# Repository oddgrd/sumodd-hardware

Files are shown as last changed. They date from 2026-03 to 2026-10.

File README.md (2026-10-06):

# Sumodd motherboard PCB schematic and layout

This repository holds the schematic and PCB layout files for the
[Sumodd](https://github.com/oddgrd/sumodd) mini-sumo robot motherboard, as well as documentation
for the layout of the various components. For the custom ranging sensor daughterboards, see the
[Auge repo](https://github.com/oddgrd/auge).

When a new iteration of the PCB is manufactured, the latest included commit is tagged with a
version number, e.g. `v0.3`. All parts are specified with Digikey part numbers, in the symbols
`Part number` field.

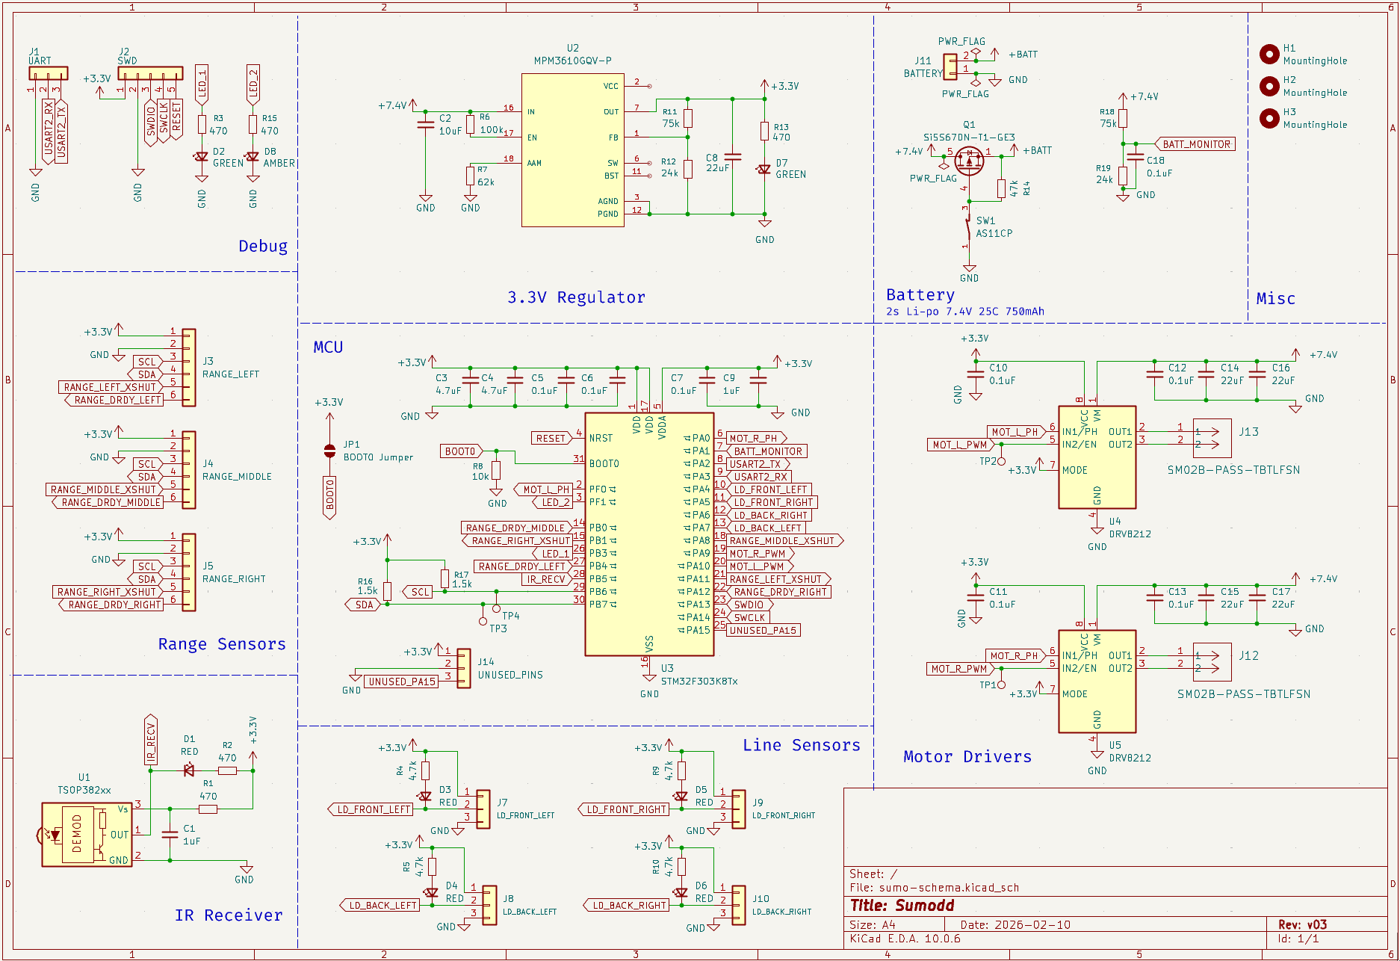
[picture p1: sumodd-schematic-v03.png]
Sumodd motherboard schematic


## PCB stackup

The board has four copper layers, with a total thickness of 1.6mm.

1. F.Cu — components, signal traces and power traces
2. In1.Cu — GND plane
3. In2.Cu — 3.3V power plane
4. B.Cu — signal routing overflow

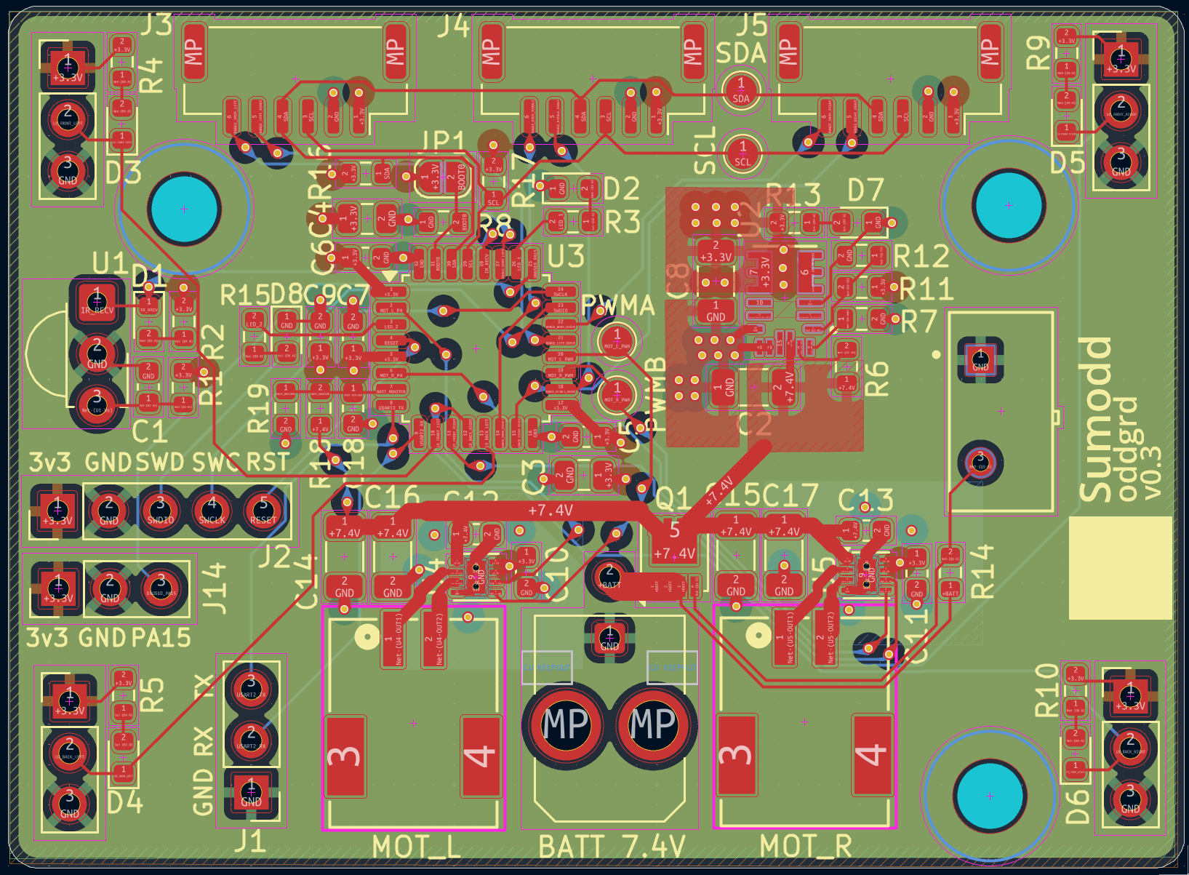
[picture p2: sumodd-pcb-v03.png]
Sumodd motherboard pcb layout


# Power

The PCB is powered by a 2s 7.4V, 25C, 800 mAh LIPO battery. This voltage is fed to a MOSFET
transistor source, the gate of which is controlled by a SPST switch that connects the gate to 
ground when closed, and a pullup resistor that connects the gate to source when opened. The
transistor drain feeds a 7.4V power rail on the top layer, which connects directly to the motor
driver VM input.

The MCU and other components want a stable 3.3V, so we use a MPM3610AGQV-P buck converter
configured to step down the battery input voltage, to feed the 3.3V power plane on the third layer.

To support the high current draw of the motor drivers, up to 2A continuous each, a [Molex Micro-Fit
3.0](https://www.molex.com/en-us/products/part-detail/430450221) connector is used for the battery,
which is rated for 8.5A.

### MPM3610 Synchronous Step-Down Converter

Datasheet: https://cdn-learn.adafruit.com/assets/assets/000/127/631/original/MPM3610GQV-Z.pdf?1707519066

The MPM3610 is implemented as documented in the typical applications sections of the datasheet,
figure 12, to arrive at an output of 3.3V, while following the PCB layout guidelines in figure 10
(screenshot below).

### Layout 

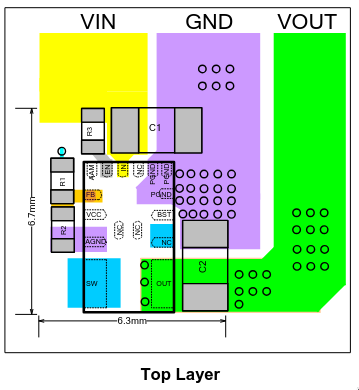
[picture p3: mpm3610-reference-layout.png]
MPM3610 reference layout


- The EN (enable) pin is connected to IN (VIN) with a 100k resistor, to pull EN high when the device is
powered.
- There is a 10 uF input capacitor on the IN (VIN) pin. The converter switches its internal mosfets
on and off at 2MHz to regulate the output voltage. The capacitor, which should be placed right next
to the device, provides a low impedance local source for the high-frequency current demands of the
converter, rather than requiring the distant battery to supply it.
    - Note: a low-ESR ceramic capacitor with X5R or X7R dielectrics is recommended in the data sheet,
    and it should be placed as close to the IC as possible. It should have an RMS current rating
    greater than half of the maximum load current. Since the regulator will only supply the MCU,
    the sensors and some LEDs, it will have a low maximum load current, around 100mA.
- There is another decoupling 22uF capacitor on the output, to stabilize the DC output voltage,
providing transient current when the load suddenly changes. Ceramic, tantalum or low ESR electrolytic
capacitors are recommended, to keep the output-voltage ripple low.
- The FB pin (feedback) is connected to the tap of a resistor divider from the output to GND,
which is used to control the output voltage. The regulator adjusts the duty cycle to keep voltage
at the FB pin at the internal reference voltage (Vref), 0.798V. Since we want 3.3V, we need a
divider which leads to 0.8V at the tap when output is 3.3V. We use a 75k and a 24k resistor:
`VOUT = 0.8 × (1 + 75k/24k) ≈ 3.3V`. This matches the recommended values from the datasheet.
    - Note: the resistor divider should be placed as close to FB as possible, any noise on the
    trace can lead to incorrect adjustment of output voltage. Vias should not be placed on the
    FB traces.
- The AAM pin is pulled to GND through a 62k resistor, as recommended in the datasheet for 8V
input, which puts the MPM3610 into power-save mode. In this mode it switches at a lower frequency
during periods of low load, relying on the output capacitor to fill in the gaps, but during periods
of high load it will transition to CCM (continuous conduction mode) and switch at max frequency.
Read more about the modes in the datasheet, page 13.
- A LED with a 4.7k series resistor is connected from OUT to GND, lighting when the converter is
powered and supplying the 3.3V output.

Note: the PGND, IN and OUT paths should have short, direct and wide traces.

### Battery monitor

To be able to monitor the battery voltage with the MCU, a resistor divider is used, with the tap of
the divider connected to an ADC channel pin on the MCU. Furthermore, we place a 0.1uF ceramic cap
from the tap to ground, to act as a low-pass filter.

Since a 7.4V battery is used, which goes up to around 8.4V fully charged, the divider is important
to ensure the MCU input stays within its 0 - 3.3V measurement range (Vref = VDDA on the
STM32F303K8T6, which will be 3.3V), for accurate measurements, as well as within its maximum
voltage rating, to avoid damaging the MCU. For more information see section 6.2 and 6.3 in the
[MCU datasheet](#stm32f303k8t6).

With a 75k R1 and a 24k R2, the divider ratio is `R2 / (R1 + R2) = 24k / 99k = 0.242`. With a fully
charged battery at 8.4V, the ADC input pin will see a voltage way below its limit:
`8.4 * 0.242 = 2.04`. If the battery power rail sees higher transient voltages, the divider gives
us a lot of headroom, for example if the voltage goes all the way to 12V: `12 * 0.242 = 2.91V`. We
could have used smaller resistors here, but these already existed in the BOM, they are also used
for the buck converter.

The voltage read in the ADC will then be converted back to the actual voltage of the battery in the
MCU firmware.

# Logic

## Microcontroller

The microcontroller is an STM32F303K8T6 see datasheet:
https://www.st.com/resource/en/datasheet/stm32f303c6.pdf

And hardware development documentation (AN4206), which was used heavily when designing the layout:
https://www.st.com/resource/en/application_note/an4206-getting-started-with-stm32f3-series-hardware-development-stmicroelectronics.pdf

The microcontroller takes its power from the 3.3V power plane, supplied by the voltage regulator.
It reads all the sensors, and controls the motors via the motor controllers.

The hardware development documentation recommends:
- A multilayer PCB with a separate layer dedicated to ground, and another layer detected to supply
(VDD), to provide good decoupling and a good shielding effect.
- The PCB layout should have separate circuits for:
    - High-current circuits
    - Low-voltage circuits
    - Digital component circuits
    - Circuits separated according to their EMI contribution. This will reduce cross-coupling
    on the PCB that introduces noise
- Unused I/O, clocks or counters should not be left free, they should be pulled high or low. This
can be done through software by configuring the pins as GPIO output.

NOTE: for more detail, see the hardware development documentation section 5, where it also
elaborates on which decoupling capacitors should be used and where.

### Layout

No external oscillator is used, so the only support components needed are decoupling capacitors.
- For both VDD/VSS pairs, we have 4.7uF (X5R, 10V) and 0.1uF (X7R, 10V) ceramic 0805 decoupling capacitors.
    - NOTE: these should be placed as close as possible to the VDD/VSS pairs, with the smaller one
    right between them. See example of this in the AN4206 doc, section 5.4.
- For VDDA, we have 0.1uF (X7R, 10V) and 1uF (X5R, 10V)  ceramic 0805 decoupling capacitors, placed
as close to the VDDA as possible,between VDDA and nearest VSS.

On this MCU, the BOOT0 pin should not float, and to boot from flash you need to pull the BOOT0 pin low.
Therefore, we pull it low with a 10k resistor by default, but we also add an open 2 pad solder jumper,
so that we can bridge BOOT0 to 3v3 if we need to boot with a bootloader. For more details on that, see
section 3 of AN4206. Furthermor, GPIO pins should not float, so unused pins should be pulled high
or low with a resistor, or configured as GPIO output in the firmware. The latter is done for this
project.

# Motor control

## Motor Drivers

https://www.ti.com/lit/ds/symlink/drv8212.pdf

The PCB has two DRV8212DSG motor drivers, controlling one motor each bidirectionally, using the
outputs as a full-bridge. The DSG package for this driver supports either a PWM interface or a
PH/EN interface.

The PWM interface requires two PWM inputs, one to each input pin, where one will
be disabled, or 0% duty cycle, and the others duty cycle will determine the speed. Flip this to
change direction.

The PH/EN interface, however, only requires one PWM input, to the first input pin, IN1. Then, the
second input pin is used to control direction. Two microcontroller pins are still needed, but the
pins can be choosen more freely, as only one needs to be PWM capable.

For this application, the PH/EN interface will be used, which is enabled by pulling the MODE pin
high on startup. This is achieved with a pullup on the MODE pin. See datasheet section 8.3.2.2
for more details, including a control truth table, 8-4.

### Layout 

For the motor connectors, JST-PA is used, which supports up to 3A, with 22 AWG wires.

The components are implemented as recommended in the typical application diagrams for the PH/EN
interface motor driving, figure 9-4. The device is placed as recommended in the layout example
for the DRL package, figure 11-2, with the thermal pad connected to the GND plane with vias.
A ground pour with stitching vias is also added on the bottom layer, underneath the driver, for
better thermal dissipation.

For each driver:
- A low ESR X7R 0603 ceramic 25V 0.1uF decoupling capacitor on VCC.
- A low ESR X7R 0603 ceramic 25V 0.1uF decoupling capacitor on VM.
- Two 22uF 25V 1206 bulk ceramic capacitors, on VM. The datasheet does not give a clear
recommendation for capacitance here, but they do talk about the importance of and considerations
for bulk capacitance in section 10.1. However, they use two 22uF 25V ceramics on the DRV821x
evaluation board ([EV board datasheet table 7-1](https://www.ti.com/lit/ug/slou540a/slou540a.pdf)),
so the same is done here. Whether this is overkill can then be measured, and in future versions one
of the caps could be removed.

All capacitors are placed as close to the device as possible, even the bulk capacitors, to minimize
loop inductance. To support the high current draw of the motors,
[JST-PA](https://www.jst-mfg.com/product/pdf/eng/ePA-F.pdf) connectors are used for the motor
connectors, which are rated for 3A.

# Sensors

The final robot will have four analog line sensors, one digital IR receiver and three digital
time-of-flight distance sensors. All of them will connect to the 3.3V power rail supplied by
the voltage regulator. They will not mount directly to the PCB, the PCB will only have connectors
for them.

## QRE1113 analog line sensors

Datasheet: https://cdn.sparkfun.com/datasheets/Sensors/Proximity/QRE1113.pdf
Breakout board schematic: https://cdn.sparkfun.com/datasheets/Sensors/Infrared/QRE1113%20Line%20Sensor%20Breakout%20-%20Analog.pdf

For each sensor we have a three pin connector, which connects to the external breakout board with
the sensors, which has the required components for the sensor itself. On the Sumodd motherboard, we
just place a LED for debugging purposes.

The LED is connected in series with a 4.7k resistor from VCC to line sensor OUT. When reflection
is low in the line sensor (no white line detected), the OUT voltage is high. When reflection is high,
the OUT voltage is LOW. When OUT is low, there is a voltage difference across the LED, from VCC to
OUT, which drives a current through the LED, lighting it.

A 330 ohm resistor was initially used for the LED, but the QRE1113 is based on a phototransistor
pulling current from VCC, through a resistor to GND. OUT connects between the resistor and
phototransistor, so as current increases through the transistor when IR reflection applies current
to its base, the voltage across the resistor drops. The issue with the 330 ohm resistor was that it
pulled more current through the LED and into OUT than the QRE1113 phototransistor could sink,
preventing OUT from going lower than about 1.5V, significantly reducing the resolution of the
signal. With a 4.7k resistor, OUT goes down to ~180mV with strong reflection, and the LED still
lights clearly.

## TSOP38238 IR receiver

Datasheet: https://cdn.sparkfun.com/assets/c/8/5/c/8/tsop382.pdf

The TSOP38238 IR receiver is implemented as documented in the typical application diagram of the
datasheet, page 1:

- A decoupling 1uF capacitor on Vs, to reduce input noise.
- A 470Ohm resistor on Vs, for protection against EOS, meaning protection against
transient spikes of high currents or voltages beyond what the device is rated for. The
datasheet recommends a resistor that is 33 Ω < R1 < 1 kΩ.
- A LED in series with a 4.7k Ohm resistor between OUT and Vs. Since OUT is pulled high when idle,
and then pulled low in pulses when receiving a signal, there will only be a voltage difference
across the LED when a signal is received, giving us a visual indication when a signal is received.

## VL53L4CD Time-of-flight sensors

Datasheet and documentation: https://www.st.com/resource/en/datasheet/vl53l4cd.pdf

The VL53L4CD sensors are placed on [custom daughterboards](https://github.com/oddgrd/auge), which
can be connected to the motherboard with 6 pin JST-GH connectors, and communicated with over I2C.
Since three ranging sensors are used, three JST-GH connectors are placed on the motherboard.

The pins are 3.3V input, GND, I2C SDA and SCL, as well as a DRDY GPIO external interrupt input
which the sensor pulls low when data is ready, and an XSHUT pin, which we can use to reprogram
the I2C address of the sensors, allowing us to run three on the same I2C bus.

I2C series resistors are placed on the custom VL53L4CD daughterboards, and the I2C pullups are
placed once on the motherboard, as recommended in the VL53L4CD datasheet, section 1.4. The pullup and
series resistor values are chosen from the datasheet recommendations, table 4, to support I2C fast
mode plus, which is 1MHz I2C. For more information, see https://github.com/oddgrd/auge#v01-testing.

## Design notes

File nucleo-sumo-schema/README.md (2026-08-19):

## Nucleo PCB

Simpler PCB for mounting nucleo and motor driver breakout boards.

### Power

- Added a bulk capacitor at the battery connector, to reduce noise from PWM, back EMF, and spikes
in current and voltage from switching direction of motors.

I tested this on the scope having all the motors running at 10% speed, with and without a bulk cap.
The scope was placed on the breadboard power rail on 7.3V+ and GND. The cap was placed on the rail
in parallel.

Without bulk capacitor:

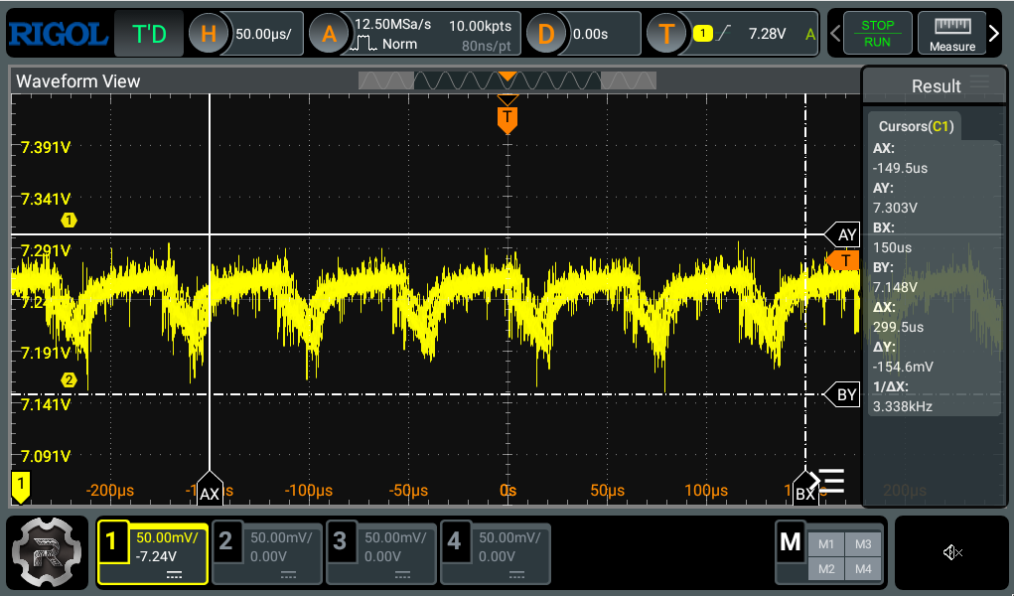
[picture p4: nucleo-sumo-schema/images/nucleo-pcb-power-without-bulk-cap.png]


With electrolytic 100 uF bulk capacitor:

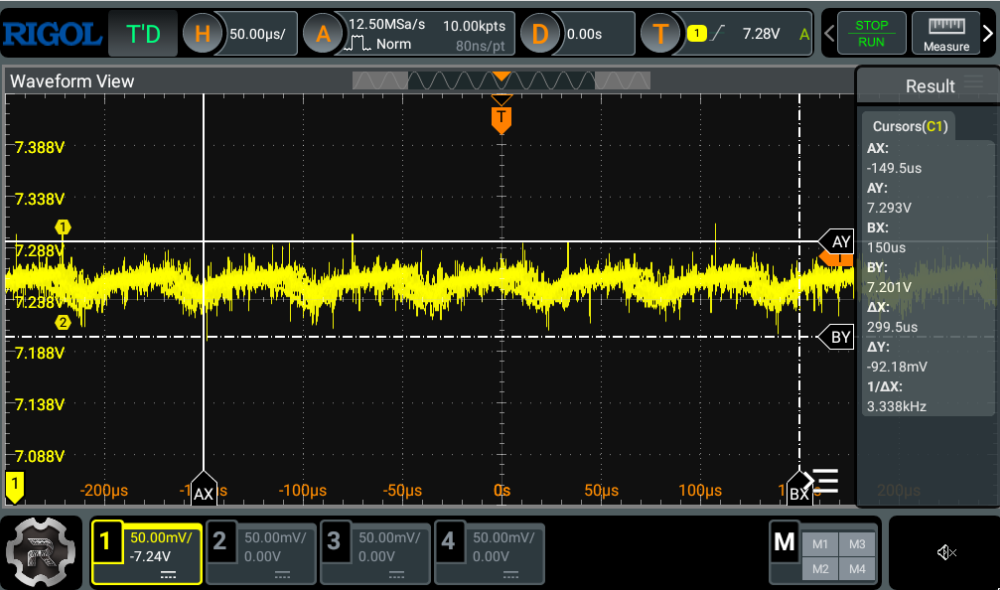
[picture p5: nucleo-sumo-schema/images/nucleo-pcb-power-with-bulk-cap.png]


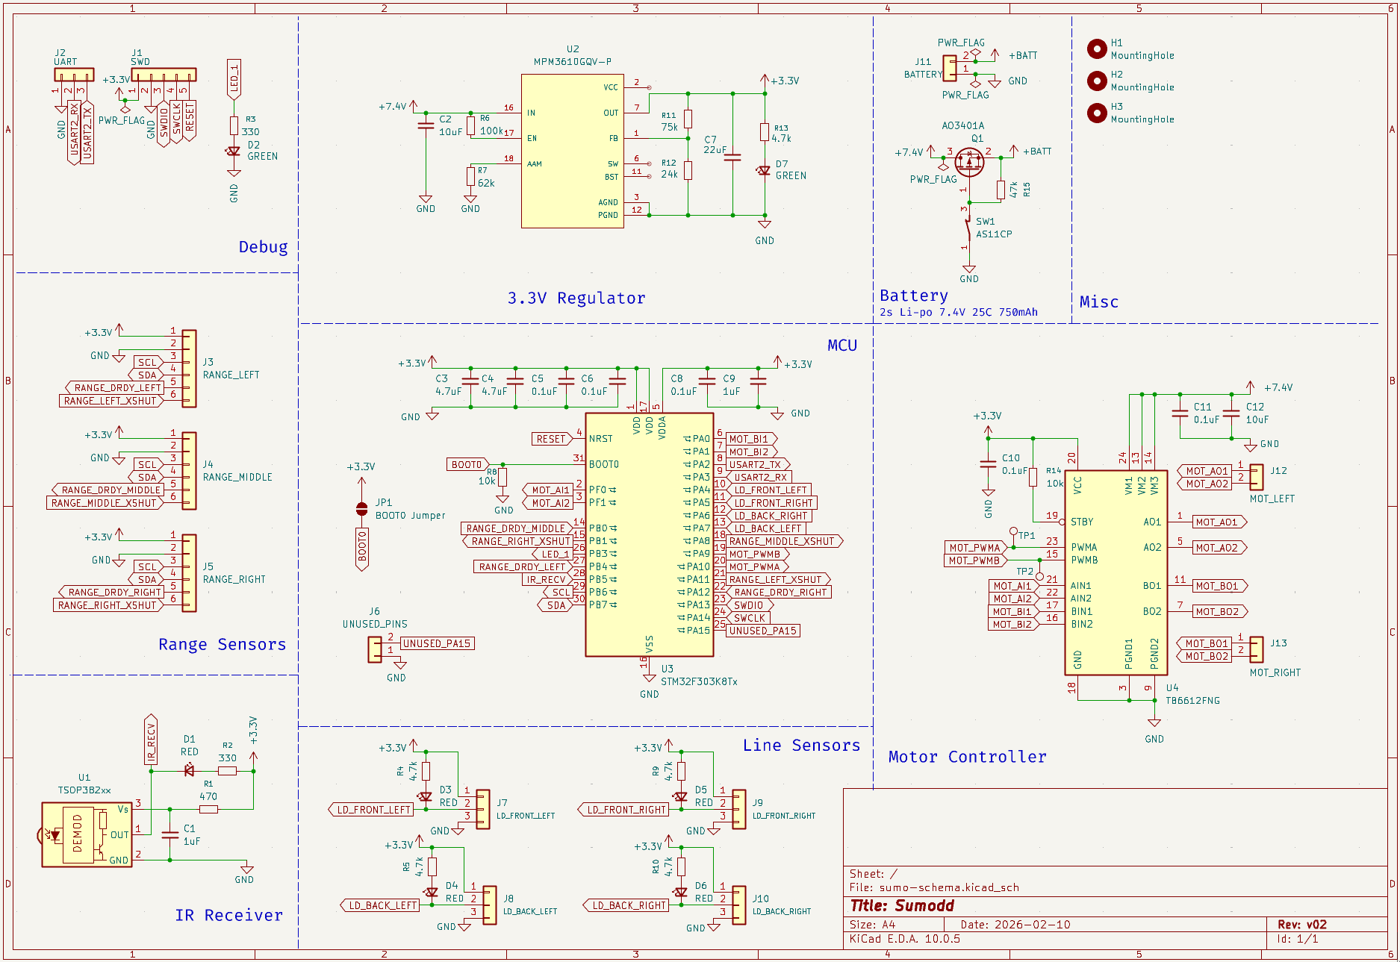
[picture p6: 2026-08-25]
sumodd-schematic-v02.png

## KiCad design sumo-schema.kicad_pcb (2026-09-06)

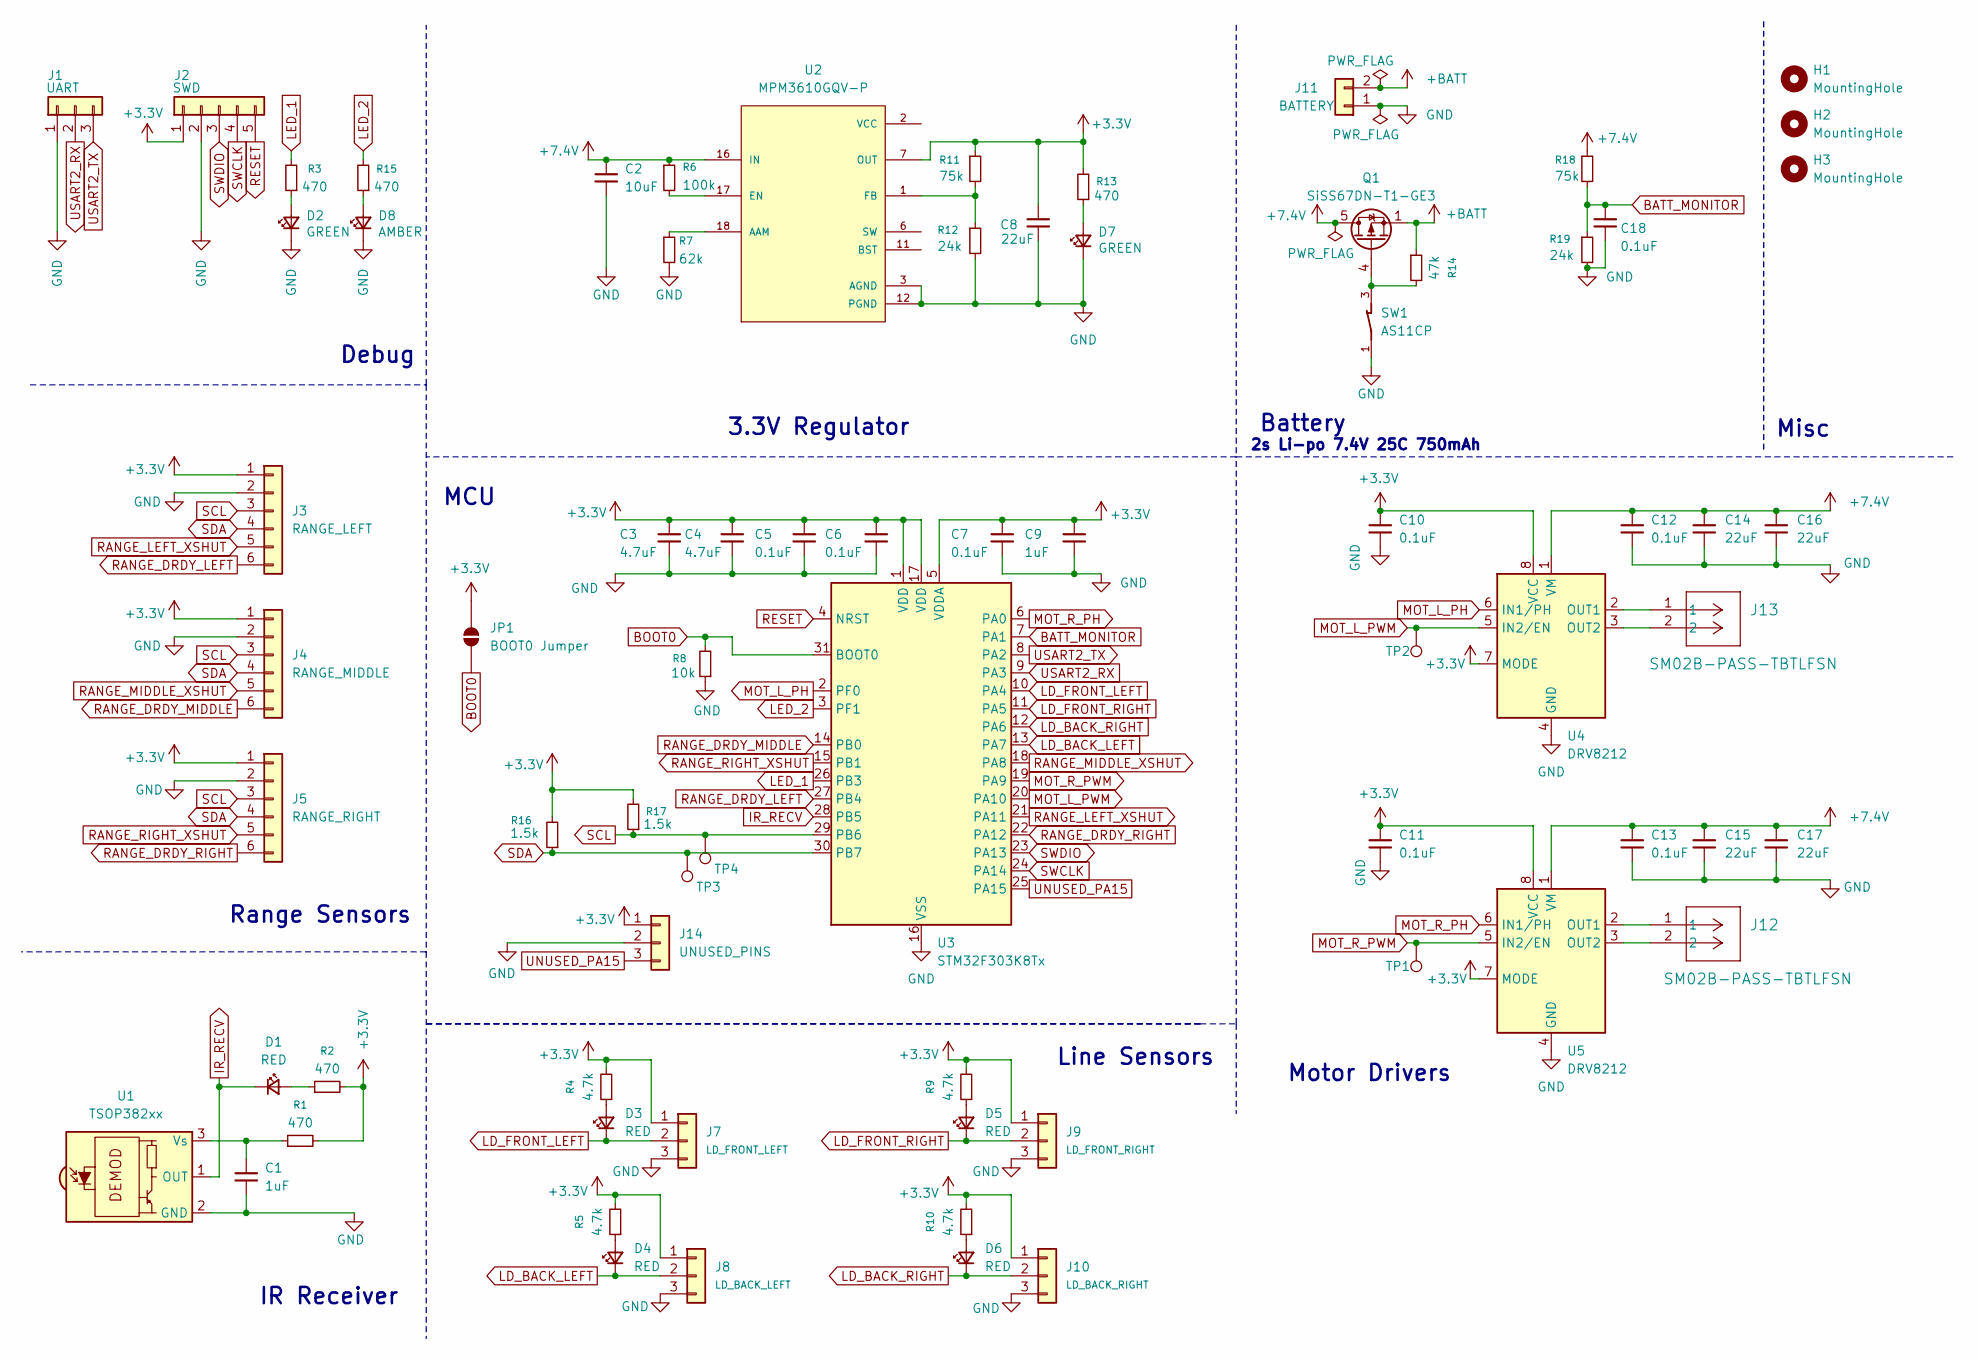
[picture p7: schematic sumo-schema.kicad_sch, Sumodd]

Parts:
C1, C9: 1uF; C_0603_1608Metric; Part Number 445-5956-1-ND
C2: 10uF; C_1206_3216Metric; Part Number 1276-6797-1-ND
C3, C4: 4.7uF; C_0805_2012Metric; Part Number 720-VJ0805G475KXQTW1BCCT-ND
C5, C6, C7, C10, C11, C12, C13, C18: 0.1uF; C_0603_1608Metric; Part Number 490-4779-1-ND
C8, C14, C15, C16, C17: 22uF; C_1206_3216Metric; Part Number 1276-3047-1-ND
D1, D3, D4, D5, D6: RED; LED_0603_1608Metric; Part Number 160-1436-1-ND
D2, D7: GREEN; LED_0603_1608Metric; Part Number 160-1435-1-ND
D8: AMBER; LED_0603_1608Metric; Part Number 160-1184-1-ND
H1, H2, H3: MountingHole; MountingHole_3.2mm_M3
J1: UART; PinHeader_1x03_P2.54mm_Vertical
J2: SWD; PinHeader_1x05_P2.54mm_Vertical
J3: RANGE_LEFT; JST_GH_SM06B-GHS-TB_1x06-1MP_P1.25mm_Horizontal; Part Number 455-1568-1-ND
J4: RANGE_MIDDLE; JST_GH_SM06B-GHS-TB_1x06-1MP_P1.25mm_Horizontal; Part Number 455-1568-1-ND
J5: RANGE_RIGHT; JST_GH_SM06B-GHS-TB_1x06-1MP_P1.25mm_Horizontal; Part Number 455-1568-1-ND
J7: LD_FRONT_LEFT; PinHeader_1x03_P2.54mm_Vertical
J8: LD_BACK_LEFT; PinHeader_1x03_P2.54mm_Vertical
J9: LD_FRONT_RIGHT; PinHeader_1x03_P2.54mm_Vertical
J10: LD_BACK_RIGHT; PinHeader_1x03_P2.54mm_Vertical
J11: BATTERY; Molex_Micro-Fit_3.0_43045-0221_2x01-1MP_P3.00mm_Horizontal; Part Number WM2672-ND
J12, J13: SM02B-PASS-TBTLFSN; CONN_SM02B-PASS_JST; Part Number 455-SM02B-PASS-TBTCT-ND
J14: UNUSED_PINS; PinHeader_1x03_P2.54mm_Vertical
JP1: BOOT0 Jumper; SolderJumper-2_P1.3mm_Open_RoundedPad1.0x1.5mm
Q1: SiSS67DN-T1-GE3; Vishay_PowerPAK_1212-8_Single; Part Number SISS67DN-T1-GE3CT-ND
R1, R2, R3, R13, R15: 470; R_0603_1608Metric; Part Number 311-470HRCT-ND
R4, R5, R9, R10: 4.7k; R_0603_1608Metric; Part Number 311-4.70KHRCT-ND
R6: 100k; R_0603_1608Metric; Part Number 311-100KHRCT-ND
R7: 62k; R_0603_1608Metric; Part Number 311-62.0KHRCT-ND
R8: 10k; R_0603_1608Metric; Part Number 311-10.0KHRCT-ND
R11, R18: 75k; R_0603_1608Metric; Part Number 311-75.0KHRCT-ND
R12, R19: 24k; R_0603_1608Metric; Part Number 311-24.0KHRCT-ND
R14: 47k; R_0603_1608Metric; Part Number 311-47.0KHRCT-ND
R16, R17: 1.5k; R_0603_1608Metric; Part Number 311-1.50KHRCT-ND
SW1: AS11CP; SW_AS11CP; PARTREV N/A
TP1: PWMB; TestPoint_Pad_D1.5mm
TP2: PWMA; TestPoint_Pad_D1.5mm
TP3: SDA; TestPoint_Pad_D1.5mm
TP4: SCL; TestPoint_Pad_D1.5mm
U1: TSOP382xx; Vishay_MINICAST-3Pin; Part Number 751-1227-ND
U2: MPM3610GQV-P; CONV_MPM3610GQV-P; PARTREV 1.01
U3: STM32F303K8Tx; LQFP-32_7x7mm_P0.8mm; Part Number 497-15828-ND
U4, U5: DRV8212; Texas_DSG0008A_WSON-8-1EP_2x2mm_P0.5mm_EP0.9x1.6mm_ThermalV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; Part Number 296-DRV8212DSGRCT-ND

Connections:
+3.3V: C3.1, C4.1, C5.1, C6.1, C7.1, C8.2, C9.1, C10.1, C11.1, J2.1, J3.1, J4.1, J5.1, J7.1, J8.1, J9.1, J10.1, J14.1, JP1.1 (A), R1.2, R2.2, R4.2, R5.2, R9.2, R10.2, R11.1, R13.2, R16.2, R17.2, U2.7 (OUT), U3.1 (VDD), U3.5 (VDDA), U3.17 (VDD), U4.7 (MODE), U4.8 (VCC), U5.7 (MODE), U5.8 (VCC)
+7.4V: C2.2, C12.1, C13.1, C14.1, C15.1, C16.1, C17.1, Q1.5 (D), R6.1, R18.1, U2.16 (IN), U4.1 (VM), U5.1 (VM)
+BATT: J11.2, Q1.1 (S), Q1.2 (S), Q1.3 (S), R14.1
BATT_MONITOR: C18.1, R18.2, R19.1, U3.7 (PA1)
BOOT0: JP1.2 (B), R8.2, U3.31 (BOOT0)
GND: C1.2, C2.1, C3.2, C4.2, C5.2, C6.2, C7.2, C8.1, C9.2, C10.2, C11.2, C12.2, C13.2, C14.2, C15.2, C16.2, C17.2, C18.2, D2.1 (K), D7.1 (K), D8.1 (K), J1.1, J2.2, J3.2, J4.2, J5.2, J7.3, J8.3, J9.3, J10.3, J11.1, J14.2, R7.2, R8.1, R12.2, R19.2, SW1.1, U1.2 (GND), U2.3 (AGND), U2.12 (PGND), U2.13 (PGND), U2.14 (PGND), U3.16 (VSS), U3.32 (VSS), U4.4 (GND), U4.9 (GND), U5.4 (GND), U5.9 (GND)
IR_RECV: D1.1 (K), U1.1 (OUT), U3.28 (PB5)
LD_BACK_LEFT: D4.1 (K), J8.2, U3.13 (PA7)
LD_BACK_RIGHT: D6.1 (K), J10.2, U3.12 (PA6)
LD_FRONT_LEFT: D3.1 (K), J7.2, U3.10 (PA4)
LD_FRONT_RIGHT: D5.1 (K), J9.2, U3.11 (PA5)
LED_1: R3.2, U3.26 (PB3)
LED_2: R15.2, U3.3 (PF1)
MOT_L_PH: U3.2 (PF0), U4.6 (IN1/PH)
MOT_L_PWM: TP2.1 (1_1), U3.20 (PA10), U4.5 (IN2/EN)
MOT_R_PH: U3.6 (PA0), U5.6 (IN1/PH)
MOT_R_PWM: TP1.1 (1_1), U3.19 (PA9), U5.5 (IN2/EN)
unnamed: D1.2 (A), R2.1
unnamed: D2.2 (A), R3.1
unnamed: D3.2 (A), R4.1
unnamed: D4.2 (A), R5.1
unnamed: D5.2 (A), R9.1
unnamed: D6.2 (A), R10.1
unnamed: D7.2 (A), R13.1
unnamed: D8.2 (A), R15.1
unnamed: Q1.4 (G), R14.2, SW1.3
unnamed: C1.1, R1.1, U1.3 (Vs)
unnamed: R7.1, U2.18 (AAM)
unnamed: R6.2, U2.17 (EN)
unnamed: R11.2, R12.1, U2.1 (FB)
unnamed: J13.1, U4.2 (OUT1)
unnamed: J13.2, U4.3 (OUT2)
unnamed: J12.1, U5.2 (OUT1)
unnamed: J12.2, U5.3 (OUT2)
RANGE_DRDY_LEFT: J3.6, U3.27 (PB4)
RANGE_DRDY_MIDDLE: J4.6, U3.14 (PB0)
RANGE_DRDY_RIGHT: J5.6, U3.22 (PA12)
RANGE_LEFT_XSHUT: J3.5, U3.21 (PA11)
RANGE_MIDDLE_XSHUT: J4.5, U3.18 (PA8)
RANGE_RIGHT_XSHUT: J5.5, U3.15 (PB1)
RESET: J2.5, U3.4 (NRST)
SCL: J3.3, J4.3, J5.3, R17.1, TP4.1 (1_1), U3.29 (PB6)
SDA: J3.4, J4.4, J5.4, R16.1, TP3.1 (1_1), U3.30 (PB7)
SWCLK: J2.4, U3.24 (PA14)
SWDIO: J2.3, U3.23 (PA13)
UNUSED_PA15: J14.3, U3.25 (PA15)
USART2_RX: J1.2, U3.9 (PA3)
USART2_TX: J1.3, U3.8 (PA2)

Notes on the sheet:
MCU
Battery
Debug
Misc
IR Receiver
Motor Drivers
Range Sensors
Line Sensors
2s Li-po 7.4V 25C 750mAh
3.3V Regulator

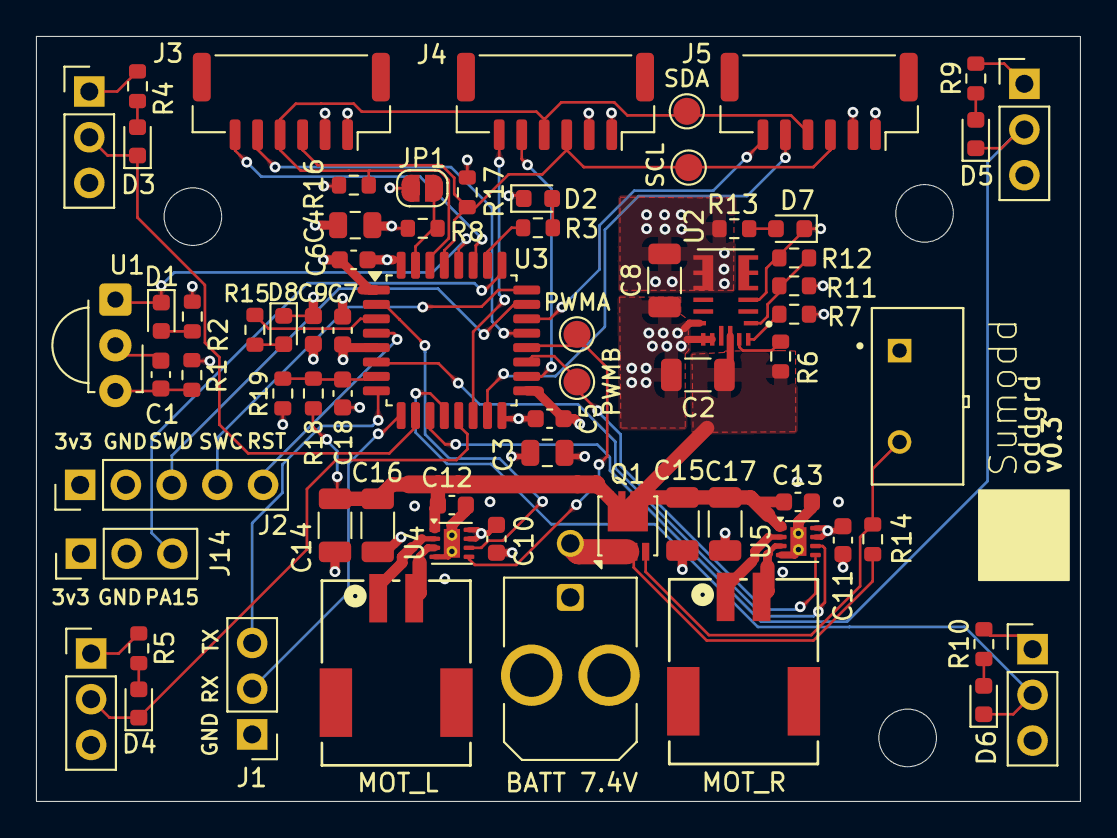
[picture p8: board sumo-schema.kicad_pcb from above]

Board: 4 copper layers, 58.0 x 42.5 mm, 73 parts (0 on the bottom side), 48 nets.

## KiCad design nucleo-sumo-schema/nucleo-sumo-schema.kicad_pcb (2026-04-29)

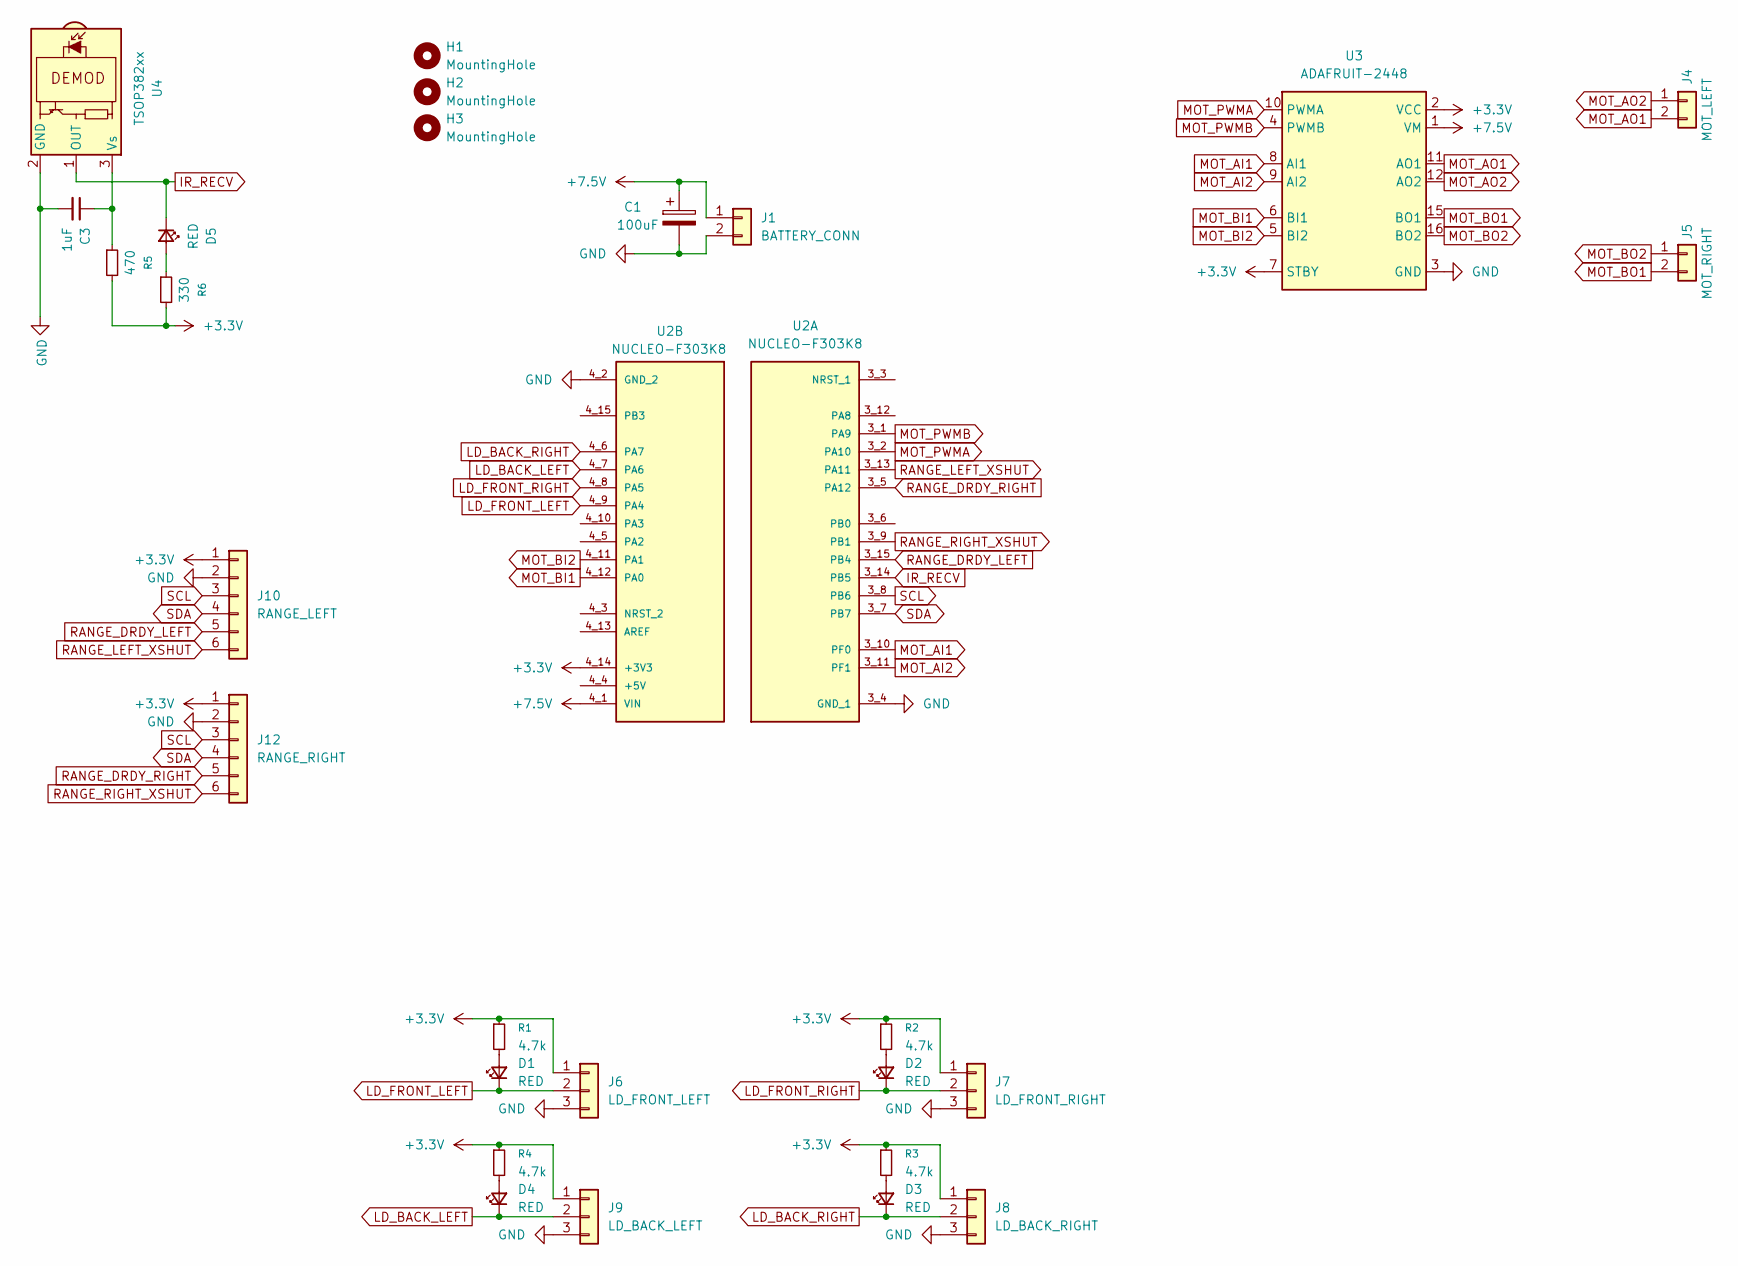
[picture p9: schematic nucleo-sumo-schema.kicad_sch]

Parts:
C1: 100uF; CP_Radial_D5.0mm_P2.50mm
C3: 1uF; C_0805_2012Metric_Pad1.18x1.45mm_HandSolder
D1, D2, D3, D4, D5: RED; LED_0805_2012Metric_Pad1.15x1.40mm_HandSolder
H1, H2, H3: MountingHole; MountingHole_3.2mm_M3_ISO7380
J1: BATTERY_CONN; JST_PH_S2B-PH-K_1x02_P2.00mm_Horizontal
J4: MOT_LEFT; JST_PH_S2B-PH-K_1x02_P2.00mm_Horizontal
J5: MOT_RIGHT; JST_PH_S2B-PH-K_1x02_P2.00mm_Horizontal
J6: LD_FRONT_LEFT; PinHeader_1x03_P2.54mm_Vertical
J7: LD_FRONT_RIGHT; PinHeader_1x03_P2.54mm_Vertical
J8: LD_BACK_RIGHT; PinHeader_1x03_P2.54mm_Vertical
J9: LD_BACK_LEFT; PinHeader_1x03_P2.54mm_Vertical
J10: RANGE_LEFT; PinHeader_1x06_P2.54mm_Vertical
J12: RANGE_RIGHT; PinHeader_1x06_P2.54mm_Vertical
R1, R2, R3, R4: 4.7k; R_0805_2012Metric_Pad1.20x1.40mm_HandSolder
R5: 470; R_0805_2012Metric_Pad1.20x1.40mm_HandSolder
R6: 330; R_0805_2012Metric_Pad1.20x1.40mm_HandSolder
U2: NUCLEO-F303K8; MODULE_NUCLEO-F303K8; PARTREV 5; DigiKey_Part_Number 497-15981-ND
U3: ADAFRUIT-2448; MODULE_ADAFRUIT-2448
U4: TSOP382xx; Vishay_MINICAST-3Pin

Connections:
+3.3V: J6.1, J7.1, J8.1, J9.1, J10.1, J12.1, R1.1, R2.1, R3.1, R4.1, R5.2, R6.2, U2.4_14 (+3V3), U3.2 (VCC), U3.7 (STBY)
+7.5V: C1.1, J1.1, U2.4_1 (VIN), U3.1 (VM)
GND: C1.2, C3.2, J1.2, J6.3, J7.3, J8.3, J9.3, J10.2, J12.2, U2.3_4 (GND_1), U2.4_2 (GND_2), U3.3 (GND), U3.13 (GND), U3.14 (GND), U4.2 (GND)
IR_RECV: D5.1 (K), U2.3_14 (PB5), U4.1 (OUT)
LD_BACK_LEFT: D4.1 (K), J9.2, U2.4_7 (PA6)
LD_BACK_RIGHT: D3.1 (K), J8.2, U2.4_6 (PA7)
LD_FRONT_LEFT: D1.1 (K), J6.2, U2.4_9 (PA4)
LD_FRONT_RIGHT: D2.1 (K), J7.2, U2.4_8 (PA5)
MOT_AI1: U2.3_10 (PF0), U3.8 (AI1)
MOT_AI2: U2.3_11 (PF1), U3.9 (AI2)
MOT_AO1: J4.2, U3.11 (AO1)
MOT_AO2: J4.1, U3.12 (AO2)
MOT_BI1: U2.4_12 (PA0), U3.6 (BI1)
MOT_BI2: U2.4_11 (PA1), U3.5 (BI2)
MOT_BO1: J5.2, U3.15 (BO1)
MOT_BO2: J5.1, U3.16 (BO2)
MOT_PWMA: U2.3_2 (PA10), U3.10 (PWMA)
MOT_PWMB: U2.3_1 (PA9), U3.4 (PWMB)
unnamed: D1.2 (A), R1.2
unnamed: D2.2 (A), R2.2
unnamed: D3.2 (A), R3.2
unnamed: D4.2 (A), R4.2
unnamed: D5.2 (A), R6.1
unnamed: C3.1, R5.1, U4.3 (Vs)
RANGE_DRDY_LEFT: J10.5, U2.3_15 (PB4)
RANGE_DRDY_RIGHT: J12.5, U2.3_5 (PA12)
RANGE_LEFT_XSHUT: J10.6, U2.3_13 (PA11)
RANGE_RIGHT_XSHUT: J12.6, U2.3_9 (PB1)
SCL: J10.3, J12.3, U2.3_8 (PB6)
SDA: J10.4, J12.4, U2.3_7 (PB7)

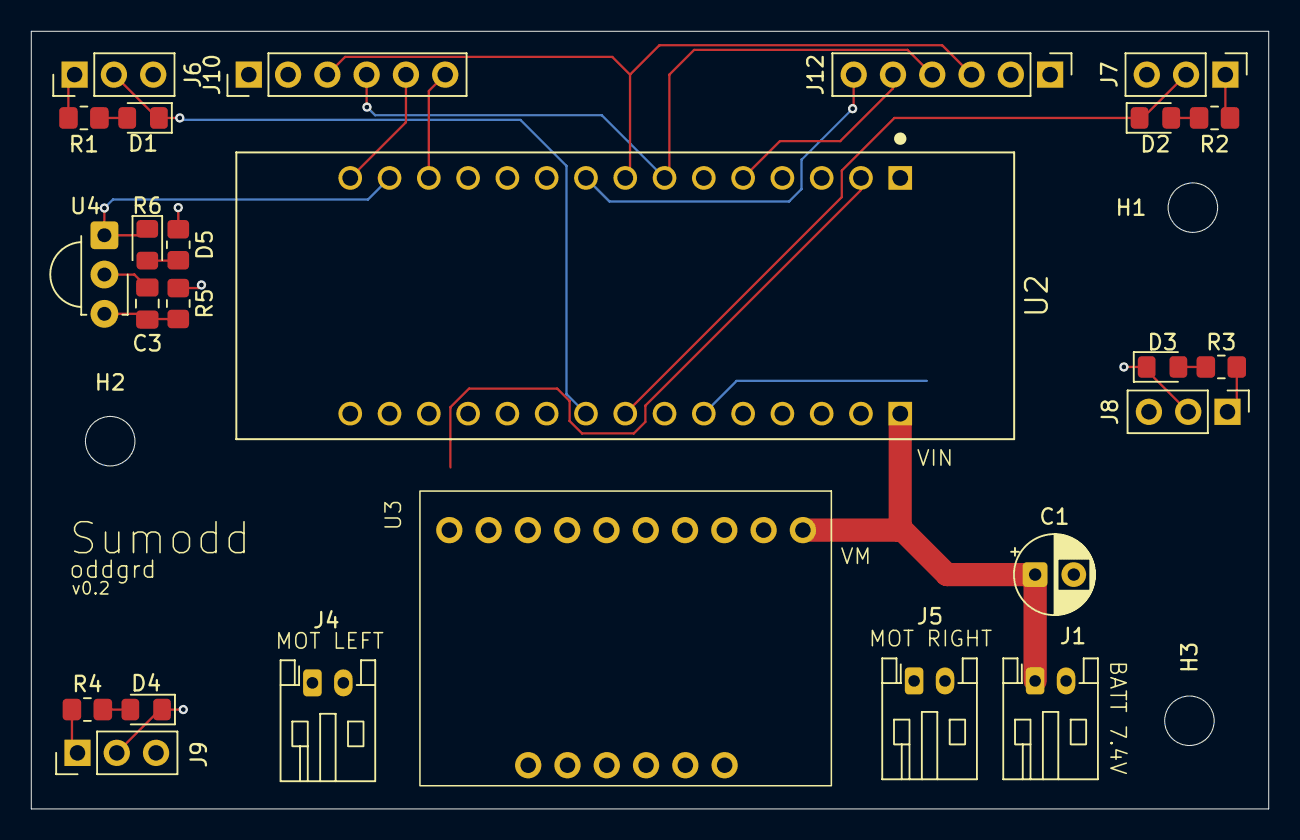
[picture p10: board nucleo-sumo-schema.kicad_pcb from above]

Board: 4 copper layers, 80.0 x 50.3 mm, 28 parts (0 on the bottom side), 30 nets.

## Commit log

2026-03-28 initial commit, v0.1 of schematic
    [sumo-schema.kicad_pcb, sumo-schema.kicad_sch]
2026-04-12 nucleo-sumo schema
    [nucleo-sumo-schema.kicad_pcb, nucleo-sumo-schema.kicad_sch, sumo-schema.kicad_pcb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]
2026-04-21 nucleo sumo schema tweaks
    [nucleo-sumo-schema.kicad_pcb]
2026-04-21 nucleo-sumo schema v0.1
    [nucleo-sumo-schema.kicad_sch]
2026-04-29 two range sensors
    [nucleo-sumo-schema.kicad_pcb, nucleo-sumo-schema.kicad_sch]
2026-05-05 reduce to single motor driver on main schema
    [sumo-schema.kicad_pcb, sumo-schema.kicad_sch]
2026-05-09 first version of sumodd without nucleo/breakouts
    [sumo-schema.kicad_pcb, sumo-schema.kicad_sch]
2026-07-07 clean up readme, non-significant adjustments to pcb
    [sumo-schema.kicad_pcb, sumo-schema.kicad_sch]
2026-07-08 update schema revision to v02
    [sumo-schema.kicad_sch]
2026-08-09 upgrade ranging sensor connectors to jst-gh
    [sumo-schema.kicad_pcb, sumo-schema.kicad_sch]
2026-08-19 pcb: change spdt power switch to spst with drain pullup
    We needed to add a pullup to source anyway, to ensure the gate stays open when switched off, the spdt switch was not stable, so it's easier to just use a spst switch
    [sumo-schema.kicad_pcb, sumo-schema.kicad_sch]
2026-08-19 pcb: reorganize symbols and footprints, add spst footprint
    also delete some older footprints and symbols that are no longer used
    [sumo-schema.kicad_pcb, sumo-schema.kicad_sch]
2026-08-19 pcb: move mpm3610 3d model into project library
    [sumo-schema.kicad_pcb]
2026-08-19 pcb & schematic: add as11cp switch symbol, footprint, 3dmodel & licensing disclaimer
    [sumo-schema.kicad_pcb, sumo-schema.kicad_sch]
2026-08-19 pcb: initial placement of as11cp switch on pcb
    [sumo-schema.kicad_pcb]
2026-08-25 docs: expand on qre1113 and mpm3160 circuits, language cleanup
2026-08-25 schematic: adopt convention of pointing power up, gnd down
    [sumo-schema.kicad_sch]
2026-08-28 schematic & pcb: swap ranging drdy and xshut connector pins
    [sumo-schema.kicad_pcb, sumo-schema.kicad_sch]
2026-08-28 schematic & pcb: reduce support component size to 0603 where sensible
    [sumo-schema.kicad_pcb, sumo-schema.kicad_sch]
2026-09-05 schematic & pcb: switch to higher current rating motor drivers
    This includes switching to higher current battery and motor connectors, as well as a higher current power switch transistor. Switching to DRV8212DSG motor drivers freed up two GPIO pins on the MCU, o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
    [sumo-schema.kicad_pcb, sumo-schema.kicad_sch]
2026-09-05 pcb & schematic: add test points for i2c, move all test points to top layer
    [sumo-schema.kicad_pcb, sumo-schema.kicad_sch]
2026-09-05 pcb & schematic: route unused pin to header, add second 22uF motor bulk caps
    [sumo-schema.kicad_pcb, sumo-schema.kicad_sch]
2026-09-05 pcb & schematic: add voltage divider battery monitor on unused pa1 adc
    Furthermore, standardize on 470 ohm led resistors, except for qre1113 resistors which need to be 4.7k to no push too much current through qre1113 phototransistor.
    [sumo-schema.kicad_pcb, sumo-schema.kicad_sch]
2026-09-05 pcb: add teardrops to all via trace connections
    [sumo-schema.kicad_pcb]
2026-09-06 pcb & schematic: swap pwm and input on motor drivers, modify symbol
    Furthermore, the via drill diameter in the drv8212 footprints is increased to 0.3mm, to reduce manufacturing cost.
    [sumo-schema.kicad_pcb, sumo-schema.kicad_sch]
2026-09-06 docs: update documentation with v0.3 parts and schematic image
2026-09-06 docs: add pcb layout image with all layers
2026-10-06 docs: reference now public auge repo, fix switch part number
    [sumo-schema.kicad_sch]
